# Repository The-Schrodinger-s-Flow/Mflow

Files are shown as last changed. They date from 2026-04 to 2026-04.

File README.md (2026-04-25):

# Mflow — Automated Microfluidic Fluorescence Microscope

> **DISCLAMER: Build in 6 hours. It is a first concept. It does not work. The optics needs revision.**

> **Built at the EMBO Hack Your Microscopy Workshop · ITQB NOVA, Lisbon**

Mflow is an open, reproducible automated microfluidic staining and imaging platform for **live/dead assays in bacterial cultures**. It was designed and built during the EMBO Hack Your Microscopy Workshop at ITQB NOVA (Oeiras, Lisbon) as a response to the challenge:

> *"In-Situ Live/Dead Staining of Bacterial Cultures — build an automated microfluidic staining and imaging system for live/dead assays."*

The system combines an OpenFlexure-based microscope with dual-channel fluorescence detection, Poseidon syringe pumps, a pre-manufactured microfluidic chip, and a custom Python segmentation pipeline to quantify live vs. dead cells in real time.

---

## Table of Contents

- [Challenge Description](#challenge-description)
- [System Overview](#system-overview)
- [Bill of Materials](#bill-of-materials)
- [Hardware Assembly](#hardware-assembly)
  - [Optics](#optics)
  - [Electronics](#electronics)
  - [Microfluidics](#microfluidics)
  - [3D Printed Parts](#3d-printed-parts)
- [Software Setup](#software-setup)
  - [Microscope Control (Trappy-Scopes)](#microscope-control-trappy-scopes)
  - [Segmentation Pipeline](#segmentation-pipeline)
- [Protocol](#protocol)
- [Repository Structure](#repository-structure)
- [Team](#team)
- [License](#license)

---

## Challenge Description

The goal was to build a fully automated system capable of:

1. Flowing fluorescent viability stains over surface-adhered bacteria using microfluidics
2. Imaging the stained sample simultaneously in two fluorescence channels (green and red)
3. Automatically segmenting the images to count live cells, dead cells, and compute a live/dead ratio

**Organism:** *Bacillus subtilis*

**Stains used:**

| Stain | Target | Emission |
|---|---|---|
| SYTO 9 | All cells (live + dead) | Green (~500 nm) |
| Propidium Iodide (PI) | Dead cells only (compromised membrane) | Red (~618 nm) |

Both stains can be applied simultaneously and imaged in separate channels without cross-talk when using appropriate filters.

---

## System Overview

```
┌─────────────────────────────────────────────┐
│              Raspberry Pi 5                 │
│  ┌──────────────┐  ┌──────────────────────┐ │
│  │  Camera 1    │  │  Camera 2            │ │
│  │  (Green ch.) │  │  (Red ch.)           │ │
│  └──────┬───────┘  └──────────┬───────────┘ │
│         │    Trappy-Scopes    │             │
│         └────────────────┬────┘             │
│                          │                  │
│  ┌───────────────────────▼──────────────┐   │
│  │         Sangaboard (Pi Pico)         │   │
│  │    OpenFlexure XYZ Stage Control     │   │
│  └──────────────────────────────────────┘   │
│                                             │
│  ┌──────────────────────────────────────┐   │
│  │   CNC Control Board (Pi Pico)        │   │
│  │   Poseidon Pump A (PBS)              │   │
│  │   Poseidon Pump B (Stain mix)        │   │
│  └──────────────────────────────────────┘   │
└─────────────────────────────────────────────┘
                      │
         ┌────────────▼─────────────┐
         │  ibidi µ-Slide (chip)    │
         │  Single channel, T-inlet │
         │  Bacteria + PLL coating  │
         └──────────────────────────┘
                      │
         ┌────────────▼─────────────┐
         │  OpenFlexure Microscope  │
         │  Infinity-corrected obj. │
         │  Blue LED excitation     │
         │  Dichroic + dual filter  │
         │  2 × Raspberry Pi Cam v2 │
         └──────────────────────────┘
```

---

## Bill of Materials

### Optics & Imaging

| Item | Part Number | Qty | Notes |
|---|---|---|---|
| OpenFlexure Microscope (body) | — | 1 | FDM printed — see `freya_openscad/` for modified parts |
| Infinity-corrected objective | — | 1 | Plan achromat, compatible with OpenFlexure mount |
| Achromatic doublet lens | [Thorlabs AC127-050-A](https://www.thorlabs.com/thorproduct.cfm?partnumber=AC127-050-A) | 2 | f = 50 mm, Ø½" (12.7 mm), ARC: 400–700 nm — one per camera |
| Raspberry Pi Camera Module v2 | — | 2 | One for green channel, one for red channel |
| Blue LED (excitation) | — | 1 | ~470 nm peak |

**Thorlabs MDF05 Filter Set — FITC (SYTO 9 / Green channel)**

| Component | Spec | Role |
|---|---|---|
| MDF05-FITC Excitation Filter | CWL = 479 nm, BW = 30 nm | Bandpass for blue LED excitation |
| MDF05-FITC Dichroic Mirror | R Band: 380–497 nm · T Band: 514.5–900 nm | Primary beam splitter |
| MDF05-FITC Emission Filter | CWL = 537 nm, BW = 40 nm | Green emission bandpass |

**Thorlabs MDF05 Filter Set — Texas Red (Propidium Iodide / Red channel)**

| Component | Spec | Role |
|---|---|---|
| MDF05-TXRED Dichroic Mirror | R Band: 381–460 nm · T Band: 608–900 nm | Separates red emission arm |
| MDF05-TXRED Emission Filter | CWL = 635.5 nm, BW = 58 nm | Red emission bandpass |

### Electronics

| Item | Qty | Notes |
|---|---|---|
| Raspberry Pi 5 | 1 | Main controller — runs Trappy-Scopes, cameras, and stage |
| Raspberry Pi Pico | 1 | Controls pump CNC board and blue LED; flashed with `steppercontrol.mpy` |
| [Sangaboard](https://sangaboard.readthedocs.io/en/latest/) | 1 | OpenFlexure motor driver board (integrated Pi Pico + stepper drivers) |
| [CNC Shield](https://mikroshop.ch/pdf/CNC-Shield-Guide.pdf) | 1 | Drives Poseidon stepper motors |

### Microfluidics

| Item | Qty | Notes |
|---|---|---|
| ibidi µ-Slide (single channel) | 1 | 1 inlet, 1 outlet |
| T-connector | 1 | Splits two pump lines into single chip inlet |
| [Poseidon syringe pump](https://github.com/pachterlab/poseidon) | 2 | Open-source syringe pump driven by CNC board |
| Compatible syringe | 2 | One per pump |
| PTFE or silicone tubing | ~1 m | Connects pumps to chip |

### Reagents

| Reagent | Purpose |
|---|---|
| SYTO 9 | Fluorescent stain — all cells (green channel) |
| Propidium Iodide (PI) | Fluorescent stain — dead cells only (red channel) |
| PBS (Phosphate Buffered Saline) | Washing buffer |
| Poly-L-Lysine (PLL) | Surface coating for bacterial adhesion |

---

## Hardware Assembly

### Optics

The microscope body is based on the **OpenFlexure** design with custom filter cubes and breadboard mount.

1. Assemble the [OpenFlexure v7 microscope body](https://openflexure.org/projects/microscope/build#openflexure-microscope-v7), **without** the standard optics module.
2. Print the custom filter cubes from `freya_openscad/` and mount them in the optical path above the objective.
3. Print and attach the custom breadboard mount plate (also in `freya_openscad/`) to fix the microscope to an optical breadboard.
4. Mount the **infinity-corrected objective** in the OpenFlexure objective port.
5. Install the **blue LED** paired with the **FITC Excitation Filter** (479/30 nm) in the illumination arm.
6. Install the **FITC Dichroic Mirror** (T: 514.5–900 nm) in the primary filter cube to direct excitation toward the sample and split emission into the green path.
7. Install the **Texas Red Dichroic Mirror** (T: 608–900 nm) in the secondary cube to split off the red path, with the **Texas Red Emission Filter** (635.5/58 nm) in the red detection arm and the **FITC Emission Filter** (537/40 nm) in the green detection arm.
8. Mount one **Thorlabs AC127-050-A** achromatic doublet (f = 50 mm, Ø½") in front of each Raspberry Pi Camera v2 to focus fluorescence onto the sensor.

### Electronics

1. Connect the **Sangaboard** to the Raspberry Pi 5 via USB, and wire it to the OpenFlexure stage stepper motors. Refer to the [Sangaboard documentation](https://sangaboard.readthedocs.io/en/latest/) for pin assignments.
2. Flash `steppercontrol.mpy` onto the **Raspberry Pi Pico** and connect it to the **CNC Shield** driving the Poseidon pumps. Pin assignments are specified in the file.
3. Connect the **blue LED** to the Raspberry Pi Pico (same Pico as the pumps). The LED pin is set in `trappyconfig.yaml`.
4. Connect both **Raspberry Pi Camera v2** modules to the Raspberry Pi 5 via ribbon cables.

### Microfluidics

1. Coat the **ibidi µ-Slide** channel with **Poly-L-Lysine (PLL)** for bacterial adhesion:
   - Pipette PLL solution to fill the channel completely.
   - Allow to **dry overnight** at room temperature.
   - Rinse gently with PBS before introducing bacteria.
2. Load the bacterial culture into the chip. Allow sufficient time for adhesion.
3. Connect the **T-connector** to the single inlet of the chip.
4. Attach **Poseidon Pump Channel 1** (PBS) and **Poseidon Pump Channel 2** (SYTO 9 + PI mixture) to the two arms of the T-connector.
5. Connect the chip outlet to a waste reservoir.

### 3D Printed Parts

All custom design files are in `freya_openscad/`, designed for standard FDM printing:

| Parameter | Value |
|---|---|
| Layer height | 0.2 mm |
| Infill | 20–30% |
| Material | PLA or PETG |
| Supports | As required per part |

Open `.scad` files in [OpenSCAD](https://openscad.org/), render, and export to STL for slicing.

---

## Software Setup

### Installation

```bash
git clone https://github.com/The-Schrodinger-s-Flow/Mflow.git
cd Mflow
python install_packages.py
mv trappyconfig.yaml ~/trappyconfig.yaml
```

Then install [Trappy-Scopes](https://github.com/Trappy-Scopes/trappyscopes):

```bash
git clone https://github.com/Trappy-Scopes/trappyscopes.git
cd trappyscopes
python main.py --install
```

---

### Microscope Control (Trappy-Scopes)

The system is controlled via **[Trappy-Scopes](https://github.com/Trappy-Scopes/trappyscopes)**, configured through `trappyconfig.yaml`.

1. Edit `trappyconfig.yaml` to match your hardware. Fill in any fields marked as gaps:

```yaml
cameras:    # Raspberry Pi Camera v2 indices
blue:       # Blue LED GPIO pin (via Pi Pico)
ch1:        # Pump Channel 1 serial port
ch2:        # Pump Channel 2 serial port
stage:      # Sangaboard serial port (comment out if controlling stage via sanga-python-gui instead)
```

2. Run the main acquisition routine:

```bash
python routine.py
```

3. To launch the Sangaboard stage control GUI separately:

```bash
python sanga-python-gui.py
```

---

### Segmentation Pipeline

Located in `Segmentation/`. Takes two fluorescence images as input and outputs live/dead cell statistics.

**Inputs:**

| File | Description |
|---|---|
| `green_channel.png` | SYTO 9 image — all cells (green) |
| `red_channel.png` | Propidium Iodide image — dead cells only (red) |

**Algorithm:** Thresholding followed by **watershed segmentation** to correctly separate touching or overlapping cells. Independent masks are computed for total cells and dead cells.

**Outputs:**

| File / Output | Description |
|---|---|
| `mask_all_cells.png` | Binary mask of all cells (from green channel) |
| `mask_dead_cells.png` | Binary mask of dead cells (from red channel) |
| `overlay_live_dead.png` | Combined live/dead false-colour overlay |
| Console | Total cell count · Dead cell count · Live/dead ratio |

**Usage:**

```bash
cd <experiment-folder>
python Segmentation.py
```

---

## Protocol

### Full Experiment Procedure

| Step | Action |
|---|---|
| **Night before** | Coat ibidi µ-Slide channel with PLL. Allow to dry overnight at RT. |
| **Day of experiment** | Load bacterial suspension into chip. Allow time for adhesion. |
| **System startup** | Power on Raspberry Pi 5. Connect cameras, Sangaboard, and CNC pump board via USB. |
| **Configure** | Edit `trappyconfig.yaml` with correct port addresses and move to `~/`. |
| **Wash** | Run Pump Channel 1 (PBS) to flush away unattached bacteria. |
| **Stain** | Run Pump Channel 2 (SYTO 9 + PI mixture) to deliver fluorescent stains. |
| **Image** | Capture simultaneous dual-channel images (green + red) via `routine.py`. |
| **Analyse** | Run `Segmentation.py` on captured images to obtain live/dead counts and ratio. |

---

## Repository Structure

```
Mflow/
├── freya_openscad/       # OpenSCAD files — custom filter cubes and breadboard mount
├── Segmentation/         # Python segmentation pipeline (live/dead cell counting)
├── routine.py            # Main acquisition and automation routine (Trappy-Scopes)
├── sanga-python-gui.py   # GUI for Sangaboard stage control
├── steppercontrol.mpy    # MicroPython firmware for pump stepper + LED control (Pi Pico)
├── trappyconfig.yaml     # Trappy-Scopes hardware configuration file
├── install_packages.py   # Dependency installer
└── README.md
```

---

## References

- [OpenFlexure Microscope v7 build guide](https://openflexure.org/projects/microscope/build#openflexure-microscope-v7)
- [Sangaboard documentation](https://sangaboard.readthedocs.io/en/latest/)
- [CNC Shield wiring guide](https://mikroshop.ch/pdf/CNC-Shield-Guide.pdf)
- [Poseidon open-source syringe pump](https://github.com/pachterlab/poseidon)
- [Trappy-Scopes microscope control software](https://github.com/Trappy-Scopes/trappyscopes)
- [Thorlabs AC127-050-A — f=50 mm, Ø½" Achromatic Doublet, ARC: 400–700 nm](https://www.thorlabs.com/thorproduct.cfm?partnumber=AC127-050-A)
- [Thorlabs MDF05 Filter Sets (FITC & Texas Red)](https://www.thorlabs.com/newgrouppage9.cfm?objectgroup_id=12280)

---

## Team

Built during the **EMBO Hack Your Microscopy Workshop** at **ITQB NOVA, Oeiras, Lisbon**.

*Team: The Schrödinger's Flow*

---

## License

This project is open hardware and open source. Hardware designs are shared under **CERN OHL v2**.
Check specific software file for the licencing information.
Reproducibility is a core goal — if something is unclear, please open an issue.

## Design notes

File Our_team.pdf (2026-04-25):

Thank You!

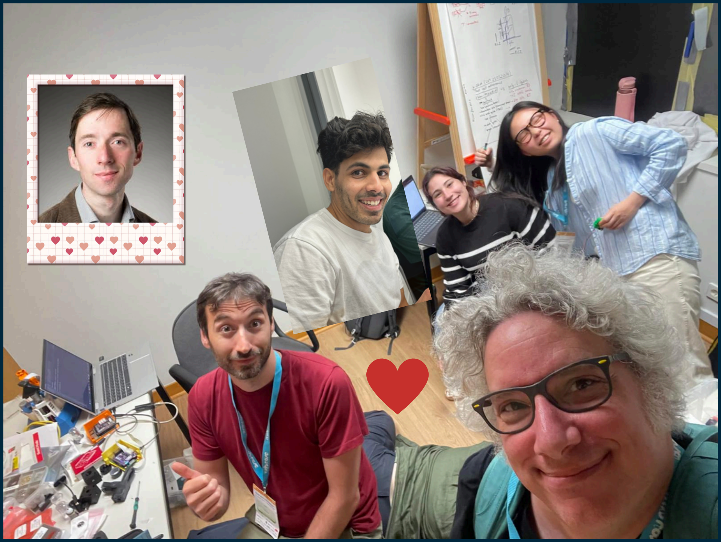
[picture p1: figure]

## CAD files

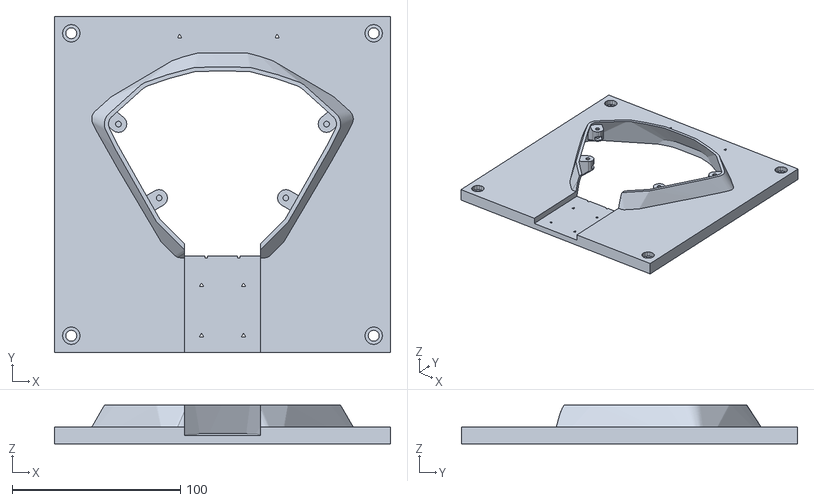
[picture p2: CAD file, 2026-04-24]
freya_openscad/microscope_mounting_plate_hq_cutout.stl
200.0 x 200.0 x 23.0

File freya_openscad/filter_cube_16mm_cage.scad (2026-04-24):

/*
 * Freya Whiteford, University of Glasgow, Apr 2026

 * Filter cube for low-cost confocal, 16mm Thorlabs cage variant
 *
 * Identical optical layout and filter parameters to filter_cube.scad, but
 * resized and re-drilled to fit the Thorlabs SR 16mm cage system:
 *   - 16mm rod spacing (centre-to-centre)
 *   - 4mm diameter cage rods
 *   - M3 clamping set screws
 *
 * Filter dimensions (excitation / emission / dichroic) are unchanged.
 *
 * Optical path:
 * 1. Excitation light enters horizontally through filter
 * 2. Dichroic at 45° reflects light downward toward sample (-Z)
 * 3. Emission light returns upward from sample (+Z)
 * 4. Emission passes through dichroic and exits through filter
 *
 * TODO: rename emission/excitation after rotating cube to match actual beam path
 * Date: 23 Apr 2026
 */


// Filter dimensions (mm) — matched to filter_cube.scad
// Excitation and emission filters are circular
excitation_filter_diameter = 12.7;  // Diameter
excitation_filter_thickness = 5.0;   // Thickness

emission_filter_diameter = 12.7;  // Diameter
emission_filter_thickness = 5.0;   // Thickness

// Dichroic mirror is rectangular
dichroic_width = 18;   // Width (x dimension)
dichroic_height = 12.7;  // Height (y dimension)
dichroic_thickness = 1.5;  // Thickness (typically thinner than filters)

// Cube dimensions — sized to host 16mm cage rods with enough wall thickness
cube_size = 26.0;  // Overall cube size (shrunk from 40.6mm; fits 16mm cage spacing)
wall_thickness = 2.0;  // Wall thickness around filters

// Thorlabs 16mm cage system mounting (SR series)
cage_rod_spacing = 16.0;  // Centre-to-centre distance (Thorlabs 16mm cage standard)
cage_rod_diameter = 4.0;  // 4mm cage rod diameter
cage_rod_hole_diameter = 4.2;  // Slightly larger for clearance

// Cage rod clamping holes (set screws to secure rods) — M3 for 16mm cage
clamp_hole_diameter = 2.5;  // M3 tap drill size
clamp_hole_depth = 6.0;  // Depth of clamping hole (shorter to fit smaller cube)

// Cutout clearance (negative = smaller cutout for friction fit)
filter_clearance = 0.05;
dichroic_clearance = 0.1;  // Slightly looser for delicate dichroic

// Slot depth for filter insertion
filter_slot_depth = 7.0;  // How far filter slides into cube (fits 5mm filter + lip)
dichroic_slot_depth = cube_size/2;  // Dichroic slot depth to centre it in cube

// Retention lip parameters
filter_lip_depth = 0.5;  // Depth of retention lip (how far it protrudes inward)
filter_lip_thickness = 1.0;  // Thickness of lip along insertion axis

// Filter window recess parameters — sized for SM05 (1/2") lens tube compatibility
filter_recess_diameter = 13.3;  // SM05 thread OD clearance
filter_recess_depth = 3.0;  // Shallower recess to suit smaller cube

// Optical path diameter
beam_diameter = 10.0;  // Clear aperture for light path

// Thorlabs post mounting (M4 metric threading) — shorter blind hole for smaller cube
post_mount_hole_diameter = 3.2;  // Drill size for M4 tap (3.3mm standard)
post_mount_depth = 10.0;  // Depth of threaded hole from -Y face
post_mount_position_z = 0;  // Z position of post mount (0 = centred)

// Print tolerances
$fn = 60;  // Smoothness of curved surfaces

// ============================================================================
// DERIVED DIMENSIONS
// ============================================================================

// Calculate positions to centre the optical paths
excitation_offset_z = cube_size / 2;
emission_offset_z = cube_size / 2;
dichroic_offset_z = cube_size / 2;

// ============================================================================
// MAIN ASSEMBLY
// ============================================================================

module filter_cube() {
    difference() {
        // Main cube body
        cube([cube_size, cube_size, cube_size], center=true);

        // Excitation path (along X axis)
        excitation_path();

        // Emission path (along Y axis)
        emission_path();

        // Dichroic slot (45° angle)
        dichroic_slot();

        // Filter insertion slots
        excitation_filter_slot();
        emission_filter_slot();

        // Thorlabs cage rod mounting holes
        cage_rod_holes();

        // Thorlabs post mounting hole (-Y face)
        post_mount_hole();
    }

}

// ============================================================================
// OPTICAL PATHS
// ============================================================================

module excitation_path() {
    // Beam path along X axis (excitation light enters from -X direction)
    // -X face is blocked
    translate([cube_size/4, 0, 0])
        rotate([0, 90, 0])
            cylinder(h=cube_size/2 + 2, d=beam_diameter, center=true);

    // Flared exit for alignment (+X side only)
    translate([cube_size/2 - 1, 0, 0])
        rotate([0, 90, 0])
            cylinder(h=2, d1=beam_diameter, d2=beam_diameter + 4, center=false);
}

module emission_path() {
    // Beam path along Z axis (emission light exits in +Z direction, toward detector)
    // Through hole on both -Z and +Z faces
    cylinder(h=cube_size + 2, d=beam_diameter, center=true);

    // Flared exit at top (+Z)
    translate([0, 0, cube_size/2 - 1])
        cylinder(h=2, d1=beam_diameter, d2=beam_diameter + 4, center=false);

    // Flared entrance at bottom (-Z)
    translate([0, 0, -cube_size/2 - 1])
        cylinder(h=2, d1=beam_diameter + 4, d2=beam_diameter, center=false);
}

// ============================================================================
// FILTER SLOTS
// ============================================================================

module excitation_filter_slot() {
    // Slot for circular excitation filter (normal to X axis)
    // Filter inserted from +X direction
    translate([cube_size/2 - filter_slot_depth/2 + 1, 0, 0]) {
        rotate([0, 90, 0]) {
            // Main slot
            cylinder(h=filter_slot_depth,
                    d=excitation_filter_diameter + filter_clearance,
                    center=true);

            // Retention lip - creates a step for filter to seat against
            // Positioned at the back of the slot (deeper inside)
            translate([0, 0, -filter_slot_depth/2 + excitation_filter_thickness/2])
                cylinder(h=filter_slot_depth - excitation_filter_thickness - filter_lip_thickness,
                        d=excitation_filter_diameter + filter_clearance + filter_lip_depth * 2,
                        center=false);
        }

        // Entry chamfer for easier insertion
        translate([filter_slot_depth/2 - 0.5, 0, 0])
            rotate([0, 90, 0])
                cylinder(h=1,
                        d1=excitation_filter_diameter + 2,
                        d2=excitation_filter_diameter + filter_clearance,
                        center=false);
    }

    // Recess in front of filter window (SM05-compatible)
    translate([cube_size/2 + 1 - filter_recess_depth/2, 0, 0])
        rotate([0, 90, 0])
            cylinder(h=filter_recess_depth, d=filter_recess_diameter, center=true);
}

module emission_filter_slot() {
    // Slot for circular emission filter (normal to Z axis)
    // Filter inserted from +Z direction (top)
    translate([0, 0, cube_size/2 - filter_slot_depth/2 + 1]) {
        // Main slot
        cylinder(h=filter_slot_depth,
                d=emission_filter_diameter + filter_clearance,
                center=true);

        // Retention lip - creates a step for filter to seat against
        // Positioned at the back of the slot (deeper inside)
        translate([0, 0, -filter_slot_depth/2 + emission_filter_thickness/2])
            cylinder(h=filter_slot_depth - emission_filter_thickness - filter_lip_thickness,
                    d=emission_filter_diameter + filter_clearance + filter_lip_depth * 2,
                    center=false);

        // Entry chamfer for easier insertion
        translate([0, 0, filter_slot_depth/2 - 0.5])
            cylinder(h=1,
                    d1=emission_filter_diameter + 2,
                    d2=emission_filter_diameter + filter_clearance,
                    center=false);
    }

    // Recess in front of filter window (SM05-compatible)
    translate([0, 0, cube_size/2 + 1 - filter_recess_depth/2])
        cylinder(h=filter_recess_depth, d=filter_recess_diameter, center=true);
}

module dichroic_slot() {
    // Slot for rectangular dichroic mirror (45° angle in XZ plane)
    // Rotated to intersect excitation (X) and emission (Z) paths
    // Dichroic redirects horizontal excitation light downward to sample
    rotate([0, 45, 0]) {
        // Main slot - extends through the cube at 45° in XZ plane
        cube([
            dichroic_thickness + dichroic_clearance,
            dichroic_width + dichroic_clearance,
            dichroic_height + dichroic_clearance
        ], center=true);
    }
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

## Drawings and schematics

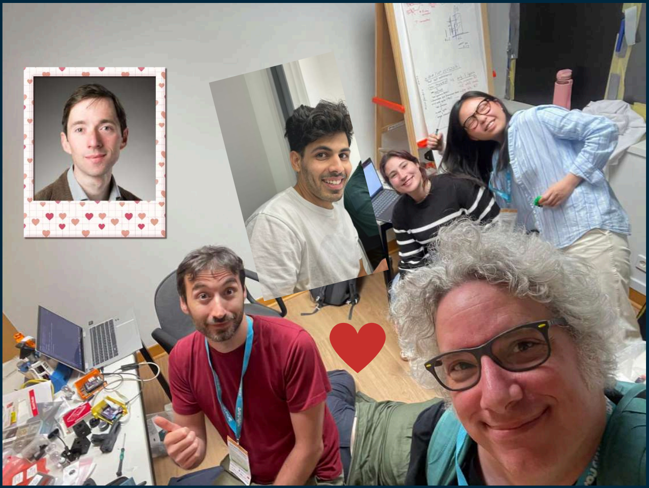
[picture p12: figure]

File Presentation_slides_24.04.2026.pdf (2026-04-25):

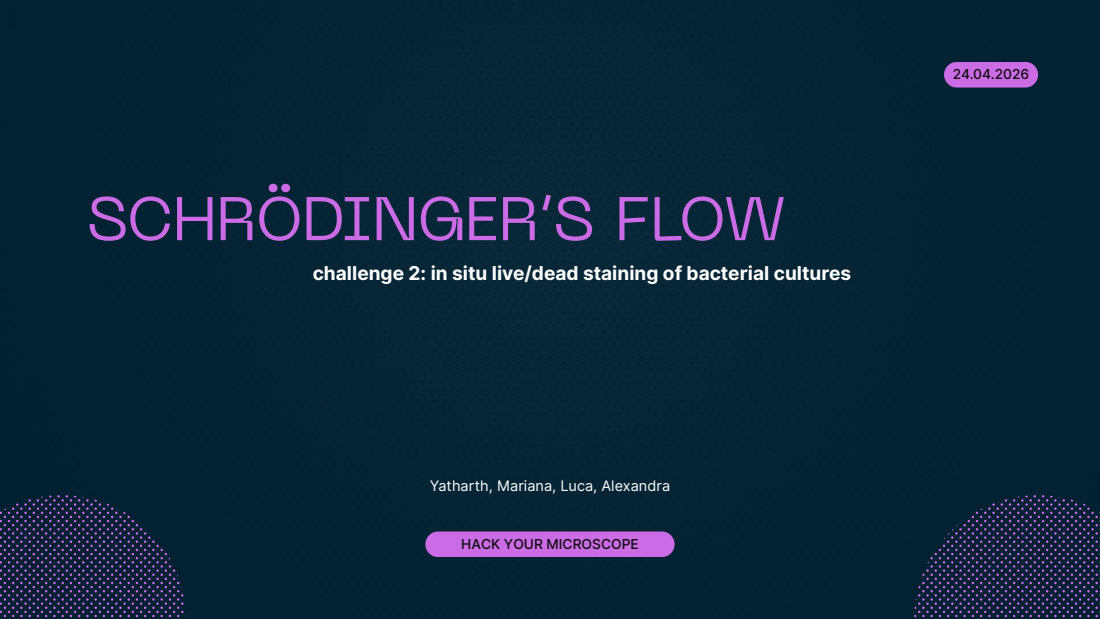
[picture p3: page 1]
SCHRÖDINGER’S FLOW

challenge 2: in situ live/dead staining of bacterial cultures

Yatharth, Mariana, Luca, Alexandra

HACK YOUR MICROSCOPE

# OBJECTIVE

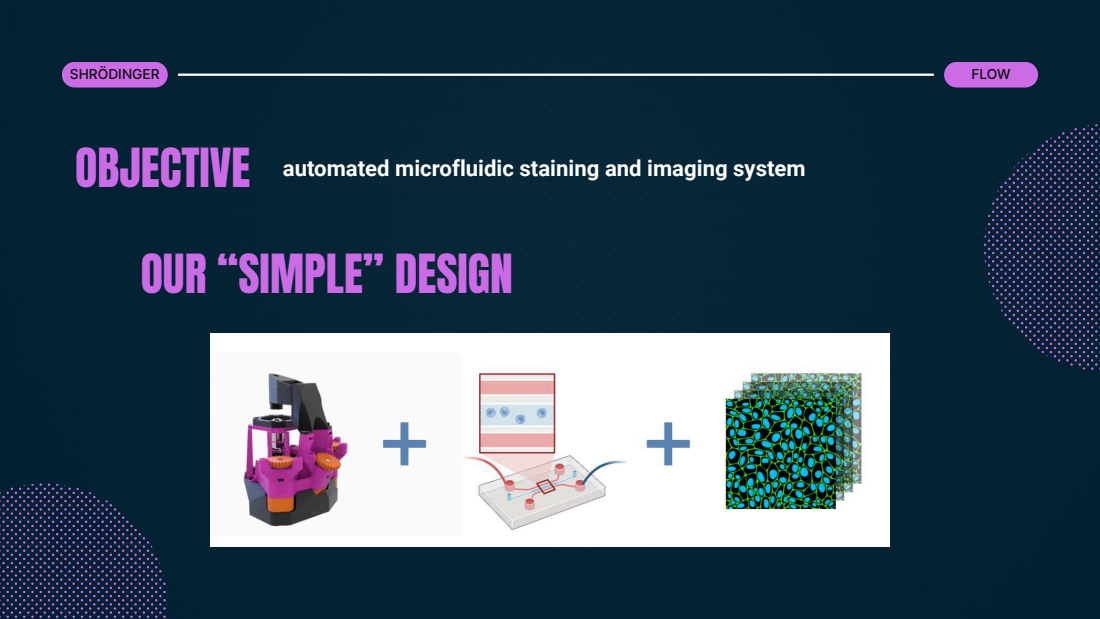
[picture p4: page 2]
SHRÖDINGER; FLOW

automated microfluidic staining and imaging system
OUR “SIMPLE” DESIGN

M

I

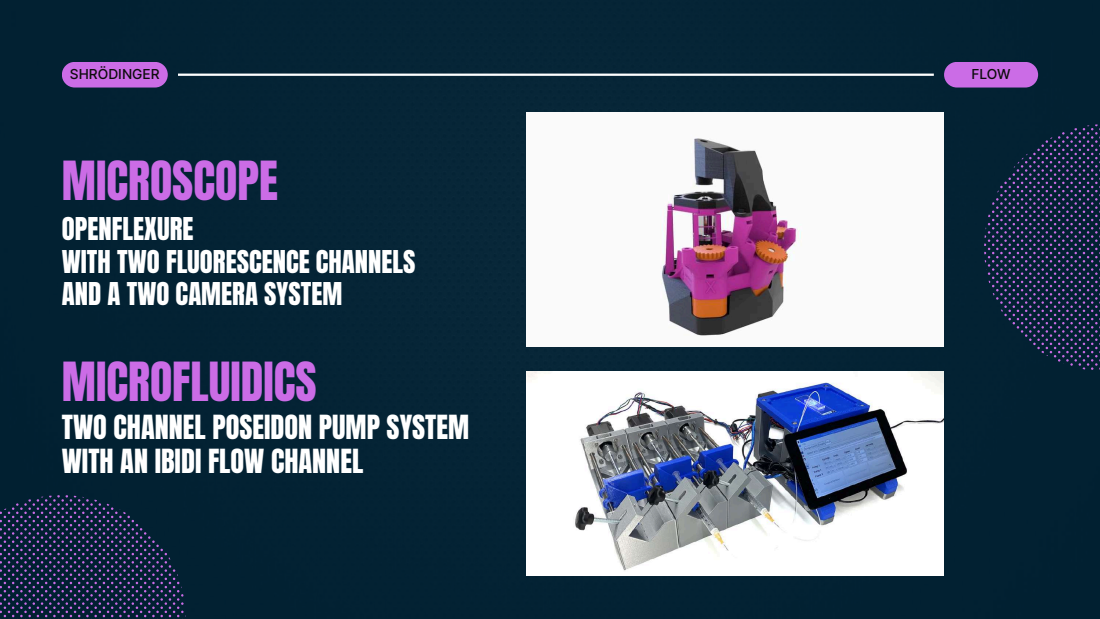
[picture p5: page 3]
DIN

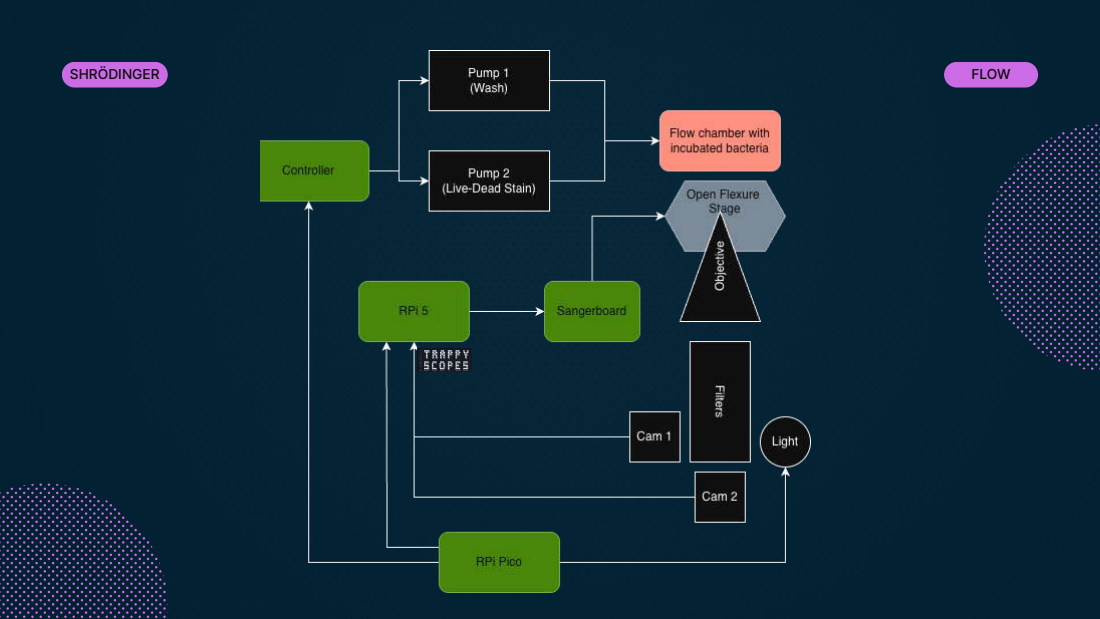
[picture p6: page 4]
SHRÖDINGER; FLOW

## BIO

L

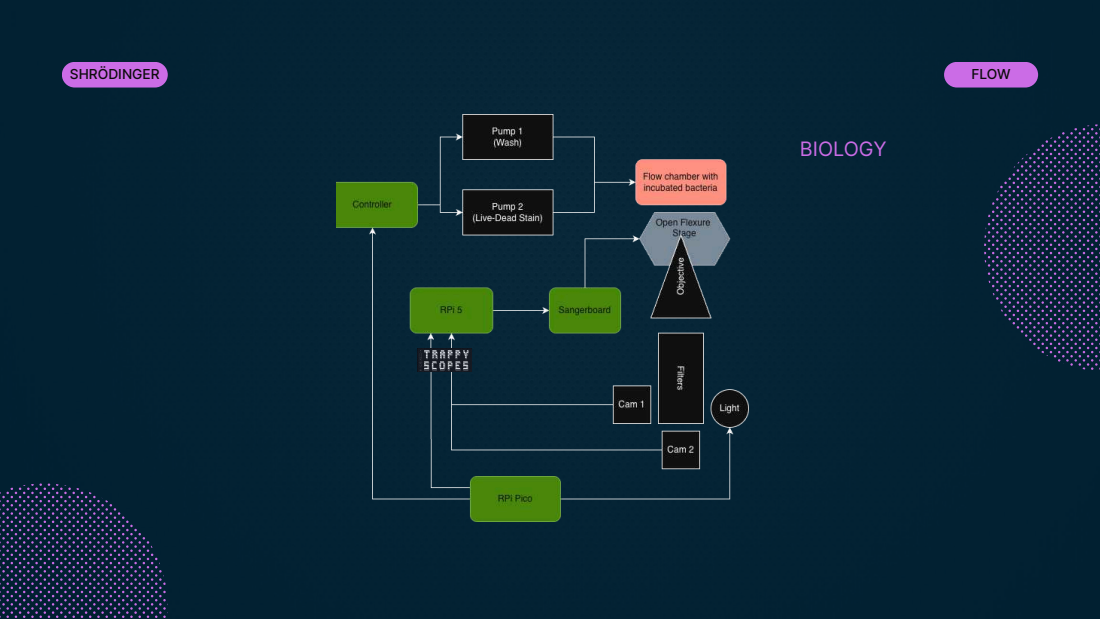
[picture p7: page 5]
DIN

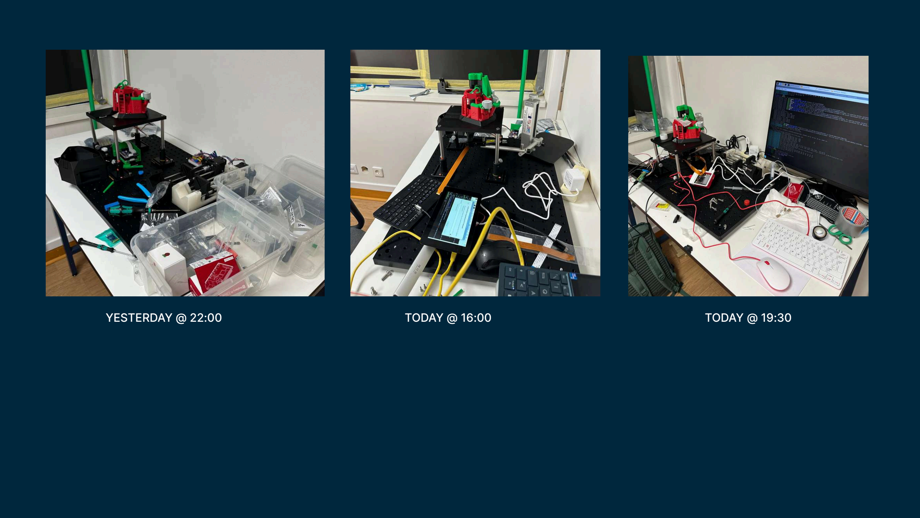
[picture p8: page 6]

YESTERDAY @ 22:00 | TODAY @ 16:00 | TODAY @ 19:30

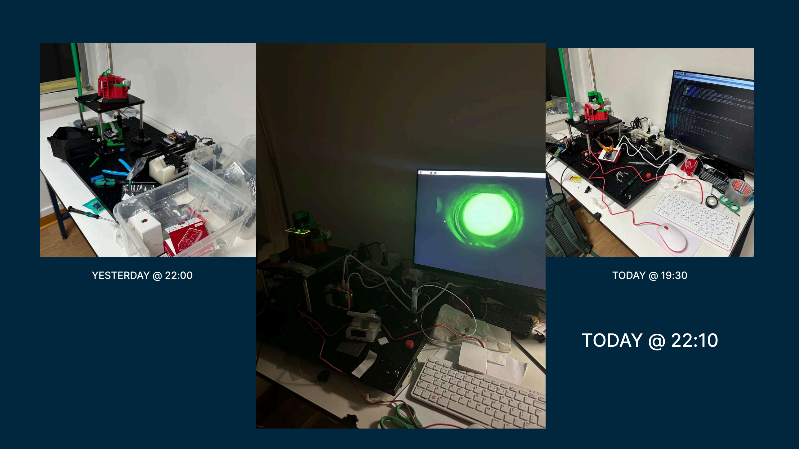
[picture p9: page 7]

YESTERDAY @ 22:00 | TODAY @ 16:00 | TODAY @ 19:30

# TODAY @ 22:10

S

E

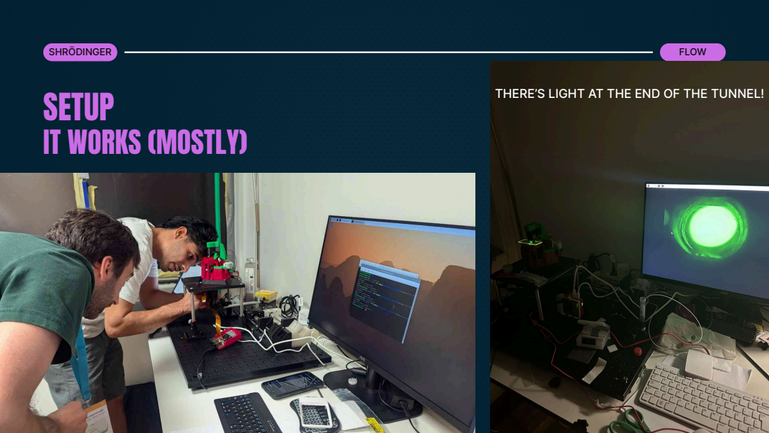
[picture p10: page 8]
DIN; LIG

# SEGMENTATION

LIVE CELLS | DEAD CELLS

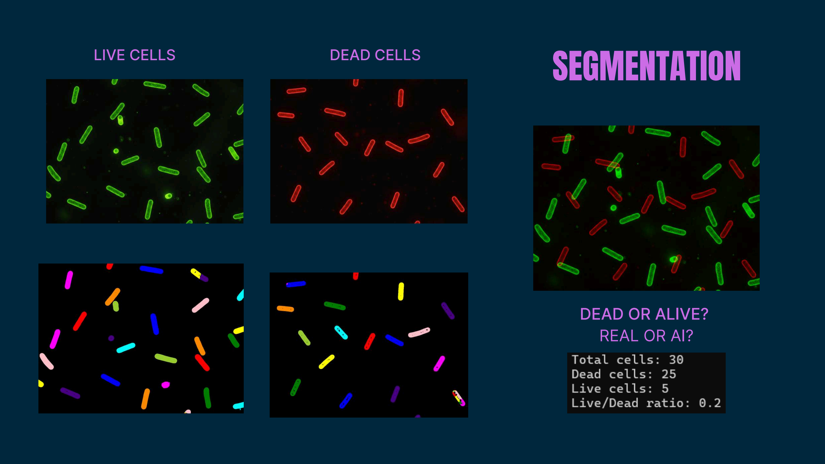
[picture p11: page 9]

## DEAD OR ALIVE?

## REAL OR AI?

# FUTURE:

# (LITTLE) OPTIMIZATION ADD A LENS (MAYBE) BUY MORE TAPE

# Thank You!
